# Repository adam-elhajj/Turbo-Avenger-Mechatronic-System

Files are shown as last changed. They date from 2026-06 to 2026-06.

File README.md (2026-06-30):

# Turbo Avenger: Autonomous Mechatronic Payload Delivery System

A high-precision, multi-actuator mechatronic system engineered for autonomous, search-and-rescue inspired payload delivery. Developed as a milestone cornerstone engineering project at the **University of Windsor**, this system automates the storage, sequencing, and deployment of three separate payloads to a static target under real-world constraints.

---

### 📺 System Verification & Demo
Click the player below to watch the **Turbo Avenger** execute its fully autonomous 3-stage delivery sequence:

Turbo Avenger Verification Demo (https://www.youtube.com/watch?v=t6WQirkNGkE)

---

## 🎯 Engineering & Performance Benchmarks
* **Targeting Precision:** Achieved an empirical accuracy of **±5 cm at a 3-meter range** (1.6% variance).
* **Autonomous Sequence:** 100% deterministic, human-out-of-the-loop sorting and deployment sequence.
* **Component Reliability:** Eliminated jamming bottlenecks using a custom dual-servo escapement architecture.
* **Fiscal Optimization:** Fully prototyped, value-engineered, and deployed within a strict **\$328 budget limit**.

---

## 🛠️ System Architecture & Visual Design

### ⚙️ Mechanical & Actuation Architecture
* **Energy Storage & Release:** Features a synchronized servo-driven energy storage system paired with a rotating latch mechanism for instantaneous power release.
* **Automated Autoloading:** Designed a dual-servo mechanical escapement subsystem to prevent multi-payload feeding failures and isolate system jams.
* **Design Validation:** Validated kinematic constraints and assembly interfaces via iterative **3D CAD modeling** and stress verification.

<table>
  <tr>
    <td><b>3D System Modeling</b></td>
    <td><b>Orthographic & Isometric Schematics</b></td>
  </tr>
  <tr>
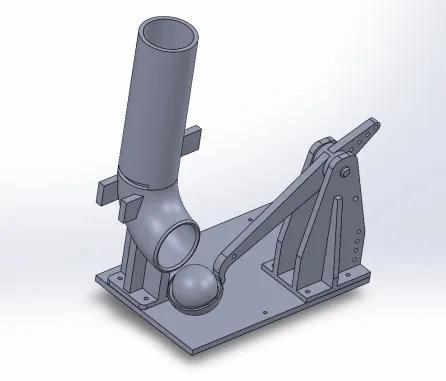
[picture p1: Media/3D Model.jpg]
3D Model
    <td></td>
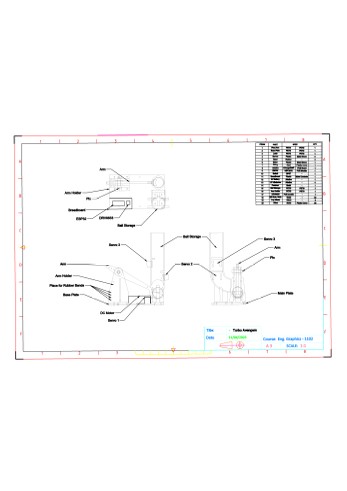
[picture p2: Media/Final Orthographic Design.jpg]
Orthographic Design
    <td></td>
  </tr>
</table>

### 🔌 Embedded Control Systems & Hardware Interface
* **Dual-MCU Architecture:** Implemented an **Arduino Uno R3** alongside an **ESP32** to handle strict real-time control, parallel processing constraints, and high-frequency state machine management.
* **State Machine & Timing Logic:** Programmed asynchronous timing models for precise actuator triggering, transition validation, and deterministic safety overrides.

<p align="center">
  <b>System Wiring & Electrical Interface Diagram</b><br>
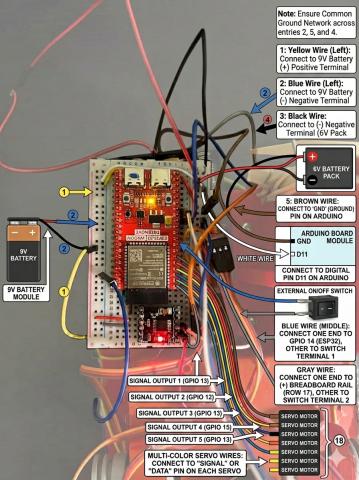
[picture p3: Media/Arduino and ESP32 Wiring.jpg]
Arduino and ESP32 Wiring Diagram
  
</p>

---

## 📂 Repository Tree Structure
```text
├── CAD-Models/                # Production Engineering Schematics
│   ├── Final Catapult assembly Team 221.dwg
│   ├── Top plate.dwg
│   └── Part_1_through_6.dwg   # Individual component layouts
├── Firmware/                  # Microcontroller Source Code
│   ├── Lunching_part_code/    # Actuator management & launch control scripts
│   └── Final-Line-Following.ino # Main path tracking algorithm script
├── Documentation/             # Engineering Specifications
│   ├── RobotCar_Part_List.pdf # Complete Bill of Materials (BOM)
│   ├── Final Proposal Report  # Technical design documentation
│   └── RFP_Amendments.pdf     # Engineering constraint compliances
└── Media/                     # Visual Assets & Portfolio Graphics
    ├── 3D Model.jpg
    ├── Arduino and ESP32 Wiring.jpg
    ├── Final Orthographic Design.jpg
    ├── Isometeric Drawing.jpg
    └── Turbo Avenger - Team#221 Poster.jpg
```

---

## 🛠️ Tools & Technologies Used
* **Languages:** C++, C (Embedded Arduino)
* **Hardware:** Arduino Uno R3, ESP32, High-Torque Servos, Electro-Mechanical Actuators
* **Software/CAD:** Autodesk AutoCAD, Git Version Control, Serial Data Analysis

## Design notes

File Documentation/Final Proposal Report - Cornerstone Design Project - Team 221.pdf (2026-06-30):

The Turbo Avenger: A Multi-Actuator Autonomous Payload Delivery System 2/52
#221

Turbo Avengers

Date: April 6, 2026
Submitted to: RHS Cornerstone Limited

Submitted by:
Adam El Hajj
Arian Navabpour
Lukas Waller
Drizzy Okunloa
Zion Odibeli

Executive Summary:

Turbo Avengers (Team 221) was commissioned by RHS Cornerstone Limited to develop an autonomous payload delivery system for hazardous search-and-rescue environments. The team engineered a servo-controlled elastic catapult featuring a synchronized three-actuator system for autonomous arming, loading, and firing. The prototype successfully met mission objectives by delivering exactly three payload units to a 30 × 40 cm target from a distance of 3 meters. With a total cost of $328.00, the system provides a robust, cost-effective, and repeatable solution. Testing confirmed that the dual-servo autoloader eliminates mechanical jams; however, precise timing control is required to maintain actuator synchronization. Overall, the Turbo Avenger demonstrates a reliable and scalable solution for autonomous payload delivery in hazardous environments.

TABLE OF CONTENTS

### 1.0 Introduction

### 1.1 Problem Statement

RHS Cornerstone Limited requires the development of an autonomous system capable of delivering emergency payloads into restricted search-and-rescue environments. The system must autonomously navigate a predefined course, stop precisely at a designated launch zone, and accurately deliver exactly three payload units into a 30 × 40 cm target area from a distance of 3 meters without human intervention. The solution must demonstrate high reliability, repeatability, and compliance with all physical and operational constraints.

### 1.2 Requirements

Functions:

The system must autonomously navigate a predefined course, stop precisely at the designated drop zone, sequentially reload payloads without failure, and execute three controlled and consistent launches to meet mission requirements.

Objectives:

The design aims to maximize launch accuracy within ±5 cm of the target, ensure highly repeatable and consistent performance across multiple trials, and minimize the likelihood of mechanical failure or jamming during operation.

Constraints:

The system is constrained to utilize elastic potential energy as the primary launch mechanism, fit entirely within the dimensional limits of the ELEGOO robotic chassis, and incorporate non-destructive mounting methods to preserve structural integrity and allow component reuse.

### 1.3 Background Research

The development of autonomous search-and-rescue systems requires the integration of reliable navigation with precise mechanical actuation. Murphy et al. (2011) emphasize that system reliability is the primary determinant of mission success, as failure in critical subsystems, specifically energy release mechanisms, which can result in total mission failure. Historically, projectile systems such as ballista-style catapults demonstrated effective methods of storing and releasing elastic potential energy. However, these systems relied heavily on human input, introducing variability in launch force, timing, and accuracy. Modern engineering solutions address these limitations through microcontroller-based automation and actuator synchronization. Smith and Jones (2022) found that replacing manual triggering mechanisms with digitally controlled systems significantly improves trajectory consistency by eliminating human-induced variability. Similarly, Lee and Patel (2019) highlight the importance of non-destructive system integration to maintain platform stability and ensure compatibility with onboard sensors and structural components. These findings had a direct impact on the design of the Turbo Avenger. The implementation of a synchronized three-actuator system, controlled by an Arduino UNO R3 and

ESP32, enables precise control of energy storage and release. The inclusion of a DRV8833 motor driver ensures accurate actuator coordination, resulting in consistent launch trajectories with an accuracy of approximately ±5 cm over a 3-meter range.

### 2.0 Proposed Design Details

### 2.1 Mechanical Architecture: Functional Description

The Turbo Avenger utilizes a pivoting launch arm powered by elastic potential energy to deliver payloads with consistent force and trajectory. The system operates using a synchronized three-actuator control system. The overall mechanical architecture of the Turbo Avenger is shown in Figure 1

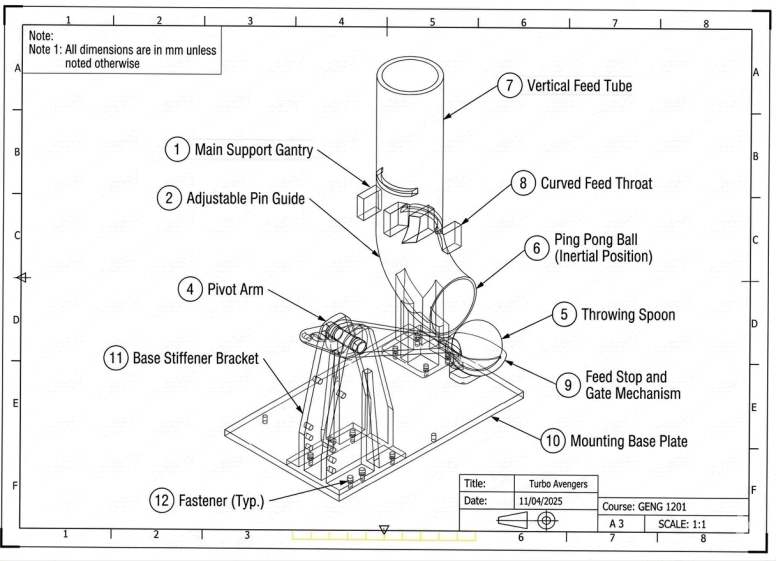
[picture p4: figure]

Figure 1: Mechanical architecture of the Turbo Avenger showing the pivoting launch arm, servo-driven pulley system, locking latch, and dual-servo autoloading mechanism.

The servo-driven pulley mechanism tensions the launch arm to a fixed and controlled position, directly supporting the objective of consistent trajectory output. This mechanism is powered through a DRV8833 motor driver, enabling reversible polarity for controlled autonomous arming and tension release. A locking servo latch secures the arm during loading and releases it on command, ensuring safe and controlled energy discharge. Additionally, a dual-servo autoloading mechanism delivers payloads sequentially, eliminating mechanical jamming and ensuring the system fulfills the requirement of reloading and launching exactly three payloads autonomously. This integrated design enables the system to perform all required functions, including autonomous navigation interfacing, precise stopping, sequential reloading, and controlled launching. The design meets all constraints by utilizing elastic potential energy, maintaining compatibility within the ELEGOO chassis dimensions, and employing non-destructive mounting techniques. Furthermore, this three-actuator architecture is inherently scalable and can be adapted for higher-load, full-scale applications such as industrial or emergency payload delivery systems while maintaining control precision and system reliability. Detailed engineering drawings are provided in Appendix B.

### 2.2 Full-Scale Concept

The full-scale system maintains the same three-actuator architecture validated by the prototype, with scaled structural components and actuation forces to support real-world deployment. The Turbo Avenger prototype represents a scaled version of an autonomous payload delivery system intended for search-and-rescue environments such as debris fields and restricted urban zones. The full-scale design extends the same three-actuator architecture to support real-world operation with increased payload capacity, durability, and range while maintaining fully autonomous functionality. In a full-scale implementation, payloads would include essential supplies such as medical kits, water, or survival materials. The autoloading mechanism can be scaled by enlarging the magazine to accommodate heavier payloads while preserving sequential, jam-free delivery. Structural components would be upgraded from PLA to high-strength materials such as carbon fibre or aerospace-grade aluminum to improve durability and reduce weight. The elastic launch system would be enhanced using higher-capacity torsion springs or reinforced tension elements to achieve greater launch distances while still satisfying the requirement to use stored elastic energy. Additionally, navigation and targeting would be improved through GPS and LiDAR integration to enable autonomous operation in complex, marker-less environments. Overall, the full-scale concept preserves the core three-actuator architecture validated by the prototype while scaling performance, materials, and control systems to meet real-world search-and-rescue requirements, all while remaining compliant with the original RFP constraints.

### 2.3 Prototype Performance

The performance of the Turbo Avenger prototype was validated through iterative trials on the simulated search-and-rescue course. The system was required to deliver three payloads into a 30 × 40 cm target area from a distance of 3 meters without human intervention. Testing demonstrated that the prototype met the required mission parameters under controlled conditions across multiple trials. The system achieved a trajectory accuracy of approximately ±5 cm, indicating consistent and repeatable launch behavior. The primary strength of the design is the high consistency of the synchronized three-actuator system. The servo-driven pulley maintains a fixed tensioning position, reducing variability between launches, while the dual-servo escapement operated reliably with no observed jams or loading failures during testing. A key limitation is the dependency on precise software timing for synchronization between the pulley release, latch mechanism, and autoloader cycle. Minor timing discrepancies in the control logic can affect launch consistency, requiring careful calibration and debugging to ensure reliable operation. Overall, the prototype met all functional requirements defined in the RFP during controlled testing.

### 2.4 Materials and Construction Methods

The mechanical components of the Turbo Avenger were modeled using SolidWorks and AutoCAD to ensure precise tolerances and proper integration of moving parts. Primary structural elements, including the pivoting arm and vertical magazine, were fabricated using Red Polylactic Acid (PLA) via 3D printing. This method was selected for its ability to produce complex geometries, support rapid prototyping, and maintain sufficient rigidity under elastic loading while minimizing weight. The system employs non-destructive mounting, using standardized stainless-steel fasteners to attach the 3D-printed base plate to the existing mounting points of the Arduino ELEGOO UNO R3 chassis. This approach preserves the integrity of the platform and allows for component reuse and modular assembly. Step-by-step assembly procedures are provided in Appendix A.

The selected materials and their functional roles are summarized in Table 2.

Table 2:

Primary Prototype Materials and Functional Applications

Material: | Application:
PLA | Pivot arm, base plate, magazine, latch
Rubber | Elastic bands and guides
Steel | Fasteners, axle, structural support
Nylon | Pulley tension string
Electronics | Arduino Uno, ESP32, motor driver, servos

### 3.0 Seventh Generation Principle Reflection

The Seventh Generation Principle originates from Haudenosaunee (Iroquois) philosophy and emphasizes that decisions made today should contribute to the well-being of future generations over a long-term horizon (EcoResolution, 2025). In engineering design, this principle is applied through considerations such as sustainability, safety, resource efficiency, modularity, and minimizing environmental impact across the system lifecycle (Murphy et al., 2011). The Turbo Avenger integrates these considerations by aligning its mechanical design, material selection, and system architecture with both present operational requirements and long-term sustainability objectives.

### 3.1 Historical Context (7 Generations Back)

Approximately 150 years ago, engineering practice during the industrial era prioritized mechanical functionality, productivity, and rapid technological advancement, often with limited attention to long-term environmental consequences or system safety. Mechanical systems from this period typically lacked modern control systems, standardized safety mechanisms, and fail-safe designs, which increased the likelihood of uncontrolled operation and resource inefficiency. This historical context highlights the evolution of engineering toward systems that emphasize reliability and safety. In response, the Turbo Avenger incorporates a locking servo latch mechanism to ensure controlled release of stored elastic energy. This design prevents unintended launches and reflects modern engineering standards for fail-safe operation. The inclusion of controlled actuation mechanisms reduces risks associated with mechanical energy storage systems and improves overall system reliability, aligning with lessons learned from earlier generations of mechanical design (Smith & Jones, 2022).

### 3.2 Present Reflection

The current design of the Turbo Avenger reflects contemporary engineering priorities, including efficiency, modularity, reliability, and responsible material usage. A key feature supporting these priorities is the use of a non-destructive mounting approach, allowing the system to be integrated with the ELEGOO chassis without permanent modification. This preserves the base platform for reuse and reduces material waste, supporting sustainable prototyping practices. In addition, the use of additive manufacturing (3D printing with PLA) enables rapid prototyping while minimizing fabrication waste compared to subtractive manufacturing methods. Although PLA is used in this prototype phase due to accessibility and ease of fabrication, its selection is consistent with iterative engineering practices that prioritize development efficiency and controlled material usage. The modular nature of the system also allows individual components to be replaced or upgraded without redesigning the entire assembly, further extending system usability and reducing long-term resource consumption (Lee & Patel, 2019).

### 3.3 Future Impact (7 Generations Forward)

Looking forward, the Turbo Avenger design is structured to support long-term adaptability, sustainability, and responsible technological development. Future iterations may incorporate biodegradable or recycled composite materials to reduce persistent environmental waste after the system’s lifecycle. Transitioning to more sustainable materials would mitigate the accumulation of non-degradable plastics and align the design with environmentally responsible engineering practices. Additionally, integrating renewable energy systems, such as solar-assisted charging, could reduce reliance on non-renewable energy sources and improve operational sustainability in remote or disaster-response environments. From a control systems perspective, upgrading the platform with sensor-based feedback mechanisms, such as ultrasonic or LiDAR sensing, would enhance adaptability in dynamic environments and reduce the need for physical redesigns. The system’s scalable architecture ensures that improvements can be implemented incrementally without replacing the entire design. This adaptability supports long-term usability and reduces lifecycle waste. Overall, the Turbo Avenger aligns with the Seventh Generation Principle by emphasizing safety, modularity, material responsibility, and forward-looking adaptability, ensuring that the design remains beneficial not only for current applications but also for future generations (Murphy et al., 2011).

### 4.0 Product Cost

The total financial investment required for the fabrication of the Turbo Avenger autonomous delivery prototype is $328.00 CAD. This cost includes the mobile navigation platform, the mechatronic actuation system, control electronics, and all structural components required for operation. A detailed breakdown of expenses, including component descriptions and procurement sources, is provided in Table 1.

Table 1:

Detailed Prototype Fabrication Cost Breakdown

Component | Description | Cost (CAD)
ELEGOO Smart Robot Kit | Mobile base with Arduino UNO R3 (ELEGOO, 2026) | $100.00
Custom 3D Printing | Red PLA material and fabrication | $141.00
Actuation System | 3× micro servo motors (Amazon, 2026) | $13.00
Control Electronics | ESP32, DRV8833 motor driver, breadboard | $36.00
Assembly Hardware | Stainless steel fasteners kit | $38.00
Total Prototype Cost | | $328.00

Note: Costs are based on current Canadian retail estimates and prototyping expenditures.

### 4.1 Cost Discussion

The total prototype cost of $328.00 CAD is considered reasonable for a functional autonomous system with integrated actuation, control, and mobility. The design leverages commercially available off-the-shelf components, which reduces development time and eliminates the need for expensive custom electronics or machined parts. The ELEGOO Smart Robot Kit provides a reliable and standardized mobile platform, allowing the team to focus resources on developing the payload delivery and actuation subsystems. Similarly, the use of 3D printing enables rapid iteration and customization of mechanical components while maintaining acceptable strength and precision for prototype validation. Although additive manufacturing represents a significant portion of the total cost, it is justified by the need for design flexibility and geometric complexity in the synchronized three-actuator mechanism. Overall, the cost reflects a balance between affordability, functionality, and scalability. The prototype demonstrates a cost-efficient engineering solution that can be further optimized for mass production through material substitution, component integration, and manufacturing process refinement.

### 5.0 Conclusions and Recommendations

### 5.1 Synthesis of Findings and Final Performance

The Turbo Avenger successfully demonstrates that a synchronized three-actuator system can achieve reliable autonomous payload delivery for search-and-rescue applications. Testing confirmed that the prototype met all primary requirements, consistently achieving a launch range of approximately 3 meters with a trajectory accuracy of ±5 cm while delivering three payloads within the designated 30 × 40 cm target area. The dual-servo electronic escapement significantly improved reliability by preventing double-feeds and eliminating jamming, enabling precise and repeatable payload release. The system also operated fully autonomously while remaining below the 1.5-meter height constraint, confirming that controlled elastic energy combined with coordinated actuation can meet both performance and safety requirements.

### 5.2 Technical Limitations and Lessons Learned

Testing identified software timing and actuator synchronization as the primary limitation. The system depends on tightly coordinated signals between the ESP32 and Arduino Uno to control the arming pulley, locking latch, and autoloader. Minor delays in execution can disrupt actuator sequencing, leading to inconsistent loading or firing. This highlights that system performance is constrained not only by mechanical design but also by control logic precision. While the hardware is structurally sound, the absence of closed-loop feedback reduces adaptability to dynamic conditions. The key lesson is that reliable mechanical systems must be supported by equally robust, real-time control to ensure consistent operation.

### 5.3 Recommendations for Implementation

Future improvements should focus on integrating real-time sensor feedback, such as ultrasonic or infrared sensing, to enable adaptive control of firing distance and improve responsiveness in changing environments. Upgrading the navigation system to incorporate GPS and LiDAR would allow operation in unstructured, marker-less environments. From a materials perspective, replacing PLA with biodegradable or recycled composites would reduce environmental impact and align the design with sustainability goals. Additionally, consolidating control into a more integrated microcontroller architecture would reduce communication delays and improve actuator synchronization. These enhancements would improve reliability, scalability, and sustainability, supporting deployment of the Turbo Avenger as a practical autonomous search-and-rescue system.

11

References

- EcoResolution. (2025, October 13). Seven generation thinking. EcoResolution. https://www.ecoresolution.earth/resources/seven-generation-thinking
- ELEGOO. (2026). Smart robot car kit documentation. https://www.elegoo.com/
- Handley, R., & Greywolf, C. (2024). The IMAGINE 7th Generation initiative. https://imagine7thg.org/
- Indigenous Corporate Training Inc. (2020, May 30). What is the Seventh Generation Principle? Working Effectively with Indigenous Peoples Blog. https://www.ictinc.ca/blog/seventh-generation-principle
- Lee, J., & Patel, R. (2019). Modular design approaches in mechatronic systems for improved reliability and maintainability. Journal of Mechatronic Systems Engineering, 12(3), 45–58.
- Murphy, R. R., Tadokoro, S., & Kleiner, A. (2011). Search and rescue robotics. In B. Siciliano & O. Khatib (Eds.), Springer handbook of robotics (pp. 1151–1173). Springer. https://doi.org/10.1007/978-3-540-30301-5_51
- Salfi-Novena, L. (2026). Lecture 10: The Seventh Generation Principle [Lecture notes]. GENG-1201, University of Windsor. Brightspace.
- Smith, A., & Jones, B. (2022). Automation of mechanical launch systems using microcontroller-based control. International Journal of Robotics and Automation, 37(2), 101–112.

12

Appendix A - Prototype Fabrication Instructions

How to Assemble and Fabricate the Turbo Avenger Prototype

### 1. Introduction

This manual provides a clear, step-by-step procedure for the assembly of the Turbo Avenger autonomous delivery system.

Target Audience: Engineering technicians or students familiar with basic hand tools and the Arduino IDE

Estimated Completion Time: 45–60 minutes

Required Equipment: Hex key set (2 mm, 2.5 mm), small Phillips screwdriver, needle-nose pliers, and a computer with Arduino IDE installed

### 2. Materials and Components List

- (1) ELEGOO Smart Robot Car Kit base
- (1) Custom 3D-Printed Base Plate (PLA)
- (1) Pivoting Launch Arm with payload cup
- (1) Vertical Magazine Tube
- (3) Micro Servos (SG90 or equivalent)
- (1) DC Motor with pulley attachment
- (4) High-tension elastic bands
- (1) Stainless steel bolt and nut kit

### 3. Assembly Procedure

Phase 1: Structural Mounting

1. Clear the top acrylic plate of the ELEGOO robot car to prevent obstruction of sensors and wheels.
2. Align the custom 3D-printed base plate with the existing mounting holes on the chassis, as shown in Figure A1.

13

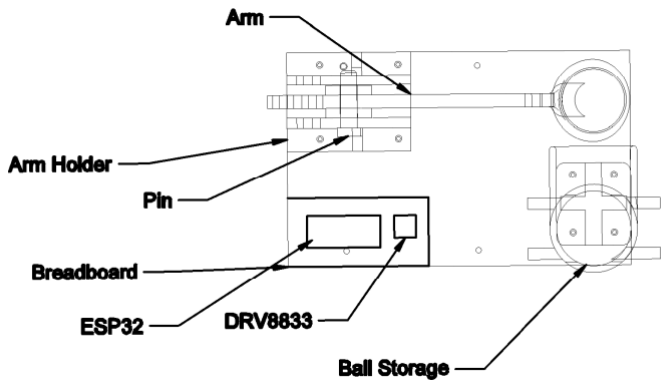
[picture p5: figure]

Figure A1: Orthographic view of the Turbo Avenger base plate alignment on the ELEGOO chassis.

3. Secure the base plate using four M3 bolts and nuts.

Note: Do not over-tighten fasteners, as PLA may crack under excessive stress.

Phase 2: Actuator Installation

4. Insert the locking servo into the designated rear slot on the base plate.
5. Attach the dual-servo autoloader to the vertical magazine tube using mounting brackets.
6. Mount the DC motor to the side frame to function as the arming pulley.

Phase 3: Launch Mechanism

7. Install the pivoting launch arm into the central axle support and secure it with the main pivot bolt.
8. Loop four high-tension elastic bands over the tensioning points on the arm and base.

Warning: Keep hands clear of the launch path during this step to prevent injury.

9. Thread the arming string from the motor pulley to the rear of the launch arm.

Phase 4: Electronics and Wiring

10. Connect the three servo signal wires to the ESP32 control interface.
11. Attach the DC motor leads to the DRV8833 motor driver.
12. Link the Arduino control pin to the ESP32 input pin to enable synchronized operation, as shown in Figure A2.

14

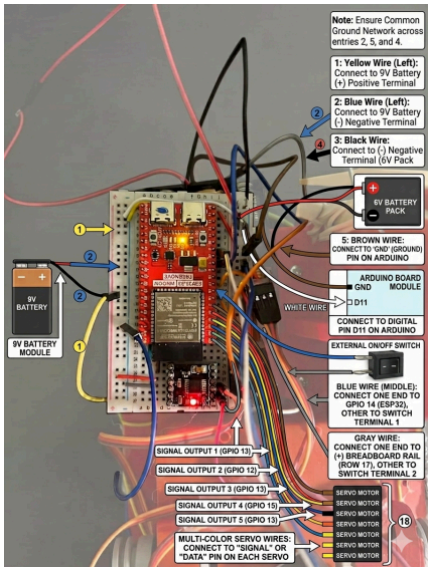
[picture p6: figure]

Figure A2: Actuator wiring configuration showing servo connections, ESP32 interface, and DRV8833 motor driver.

### 4. Final Check and Operation

13. Perform a manual dry run by rotating the pulley to confirm the arm engages the locking latch correctly.
14. Verify that all fasteners and connections are secure.
15. Upload the control program and initiate autonomous testing.

Conclusion

The assembly of the Turbo Avenger is now complete. Perform a manual “Dry Run” by rotating the pulley to ensure the arm catches the locking latch without obstruction before applying battery power. Once verified, upload the control code to initiate autonomous trials.

15

Appendix B - AutoCAD Drawing(s) of Design

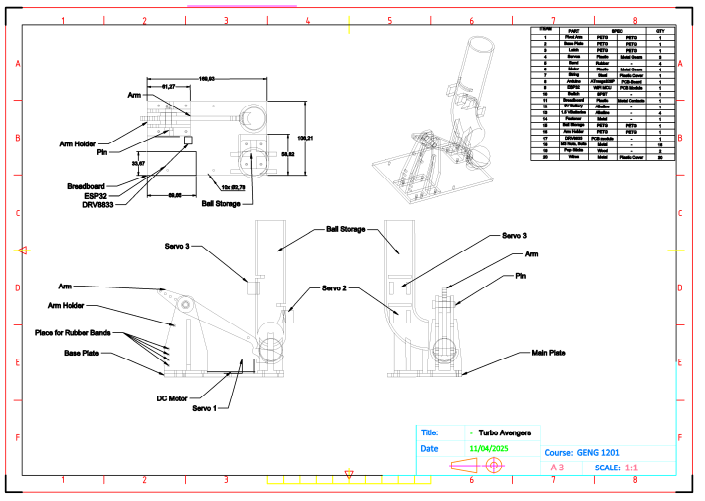
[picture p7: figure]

Figure B1: Fully dimensioned engineering drawing set of the Turbo Avenger prototype, including front, top, and right-side orthographic views and a 3D isometric model, illustrating component geometry, system integration, and compliance with chassis dimensional constraints.

16

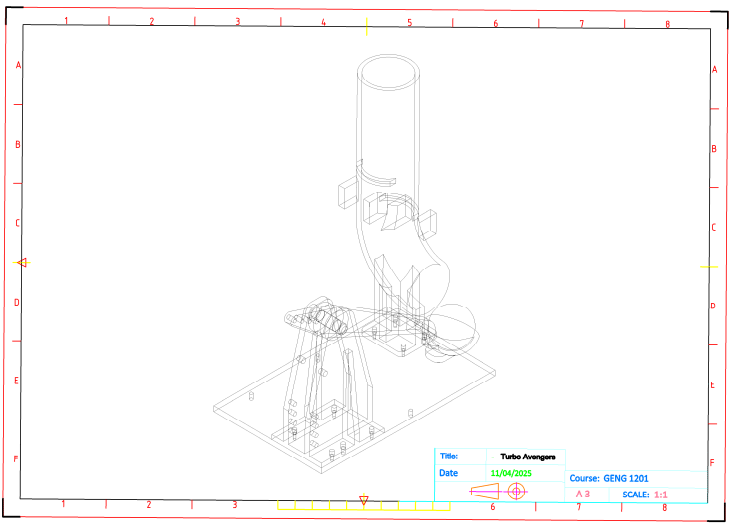
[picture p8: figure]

Figure B2: 3D isometric concept rendering of the Turbo Avenger system.

17

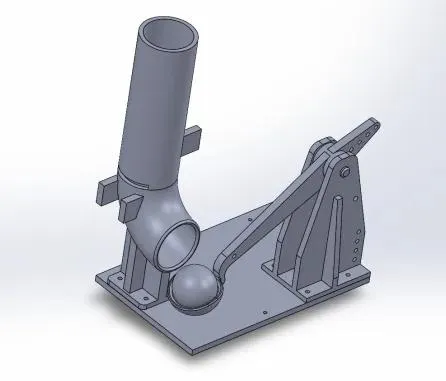
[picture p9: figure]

Figure B3: 3D AutoCad Model of the Turbo Avenger system.

18

Appendix C – Prototype Cost Breakdown Table

Table C1: Detailed Prototype Fabrication Cost Breakdown

The following table provides a comprehensive itemization of the materials and components utilized in the construction of the Turbo Avenger prototype. All costs are listed in Canadian Dollars (CAD) and reflect verified retail pricing and fabrication estimates.

Table C1:

Detailed Prototype Fabrication Cost Breakdown

Component | Technical Description & Source | Cost (CAD)
Mobile Base | ELEGOO Smart Robot Car Kit V4 (Arduino UNO R3 platform) (ELEGOO, 2026) | $100.00
Custom Structure | Red PLA 3D-printed components (pivot arm, base plate, magazine) (University of Windsor, 2026) | $141.00
Actuation System | 3× SG90 micro servo motors (Amazon, 2026) | $13.00
Control Mechatronics | ESP32 WROOM module, DRV8833 motor driver, breadboard (Electronic Supply, 2026) | $36.00
Mechanical Fasteners | Stainless steel M3/M4 bolt and nut kit (Home Hardware, 2026) | $38.00
Energy Storage | High-tension elastic bands (existing inventory) (Team Inventory, 2026) | $0.00*
TOTAL COST | | $328.00

Note. All pricing is based on Canadian retail estimates and university fabrication data. Items listed at $0.00 were sourced from existing inventory and are excluded from total procurement cost.

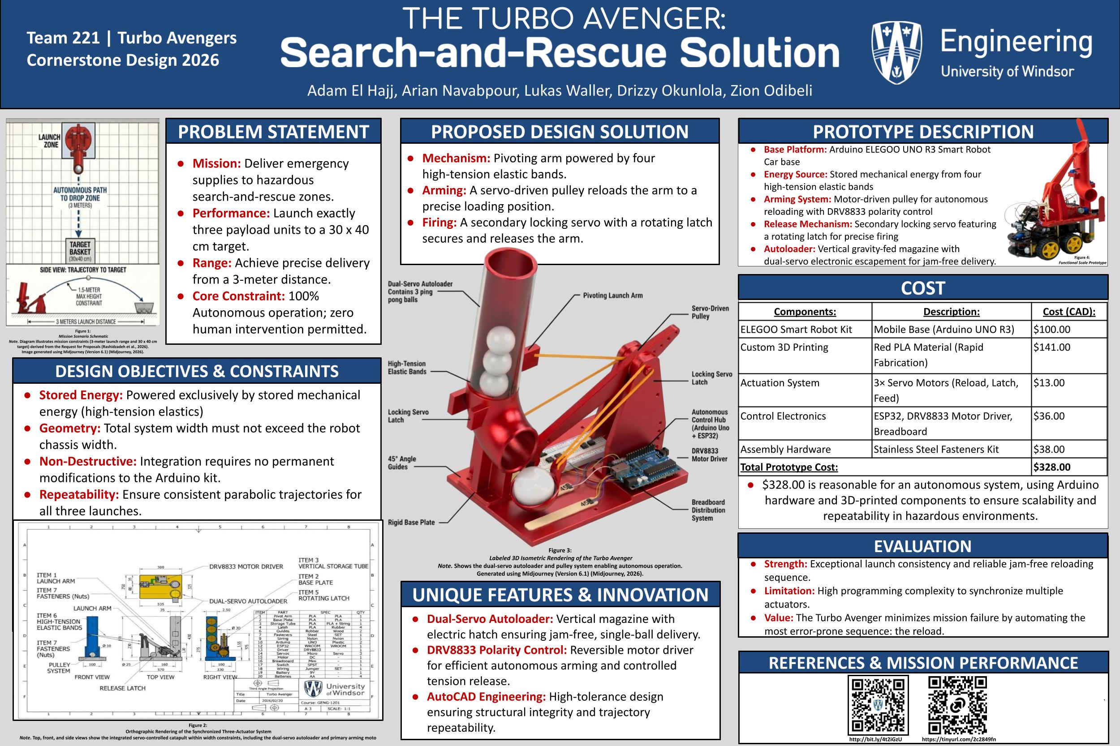
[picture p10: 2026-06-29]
Media/Turbo Avenger - Team#221 Poster.jpg

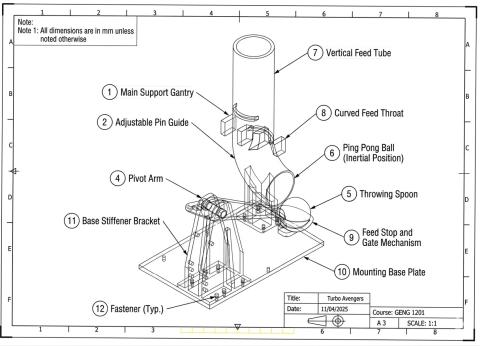
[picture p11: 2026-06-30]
Media/Isometeric Drawing.jpg

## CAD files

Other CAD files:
CAD-Models/Final Catapult assembly Team 221.dwg
CAD-Models/Part 2.dwg
CAD-Models/Part 6.dwg
CAD-Models/Part 1.dwg
CAD-Models/Part 3.dwg
CAD-Models/Top plate.dwg
CAD-Models/Final orthographic .dwg
CAD-Models/Part 4.dwg

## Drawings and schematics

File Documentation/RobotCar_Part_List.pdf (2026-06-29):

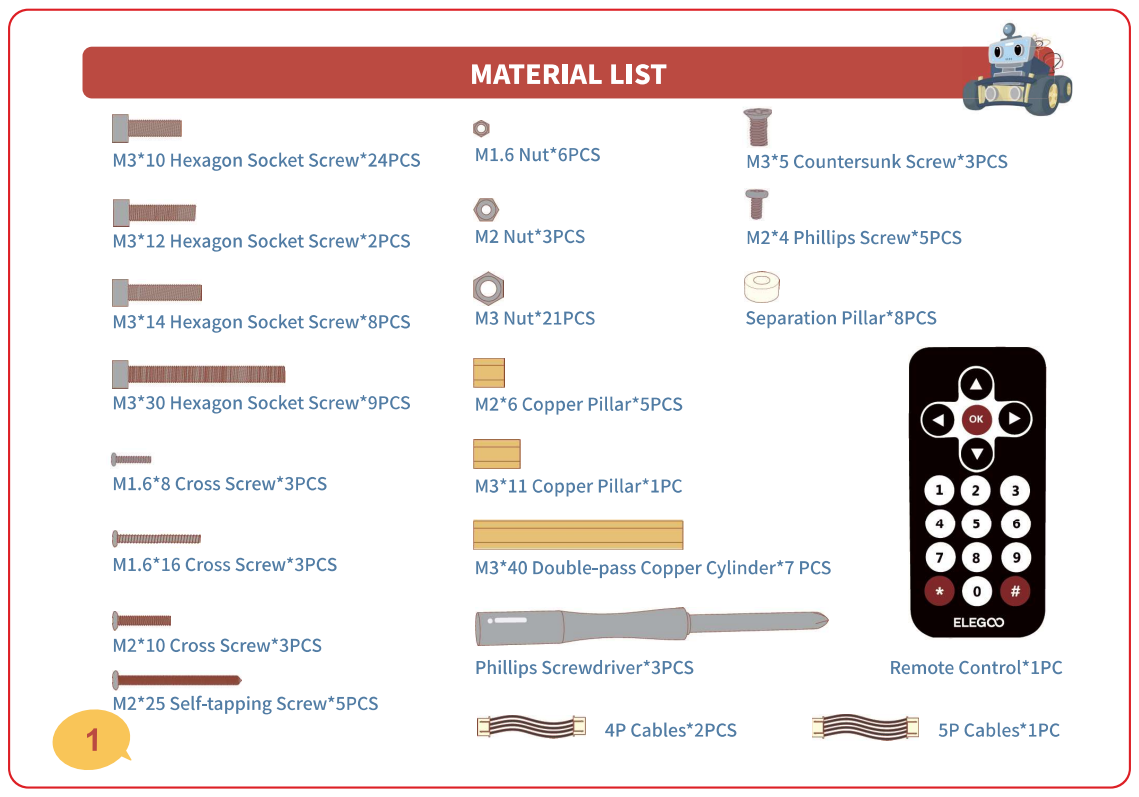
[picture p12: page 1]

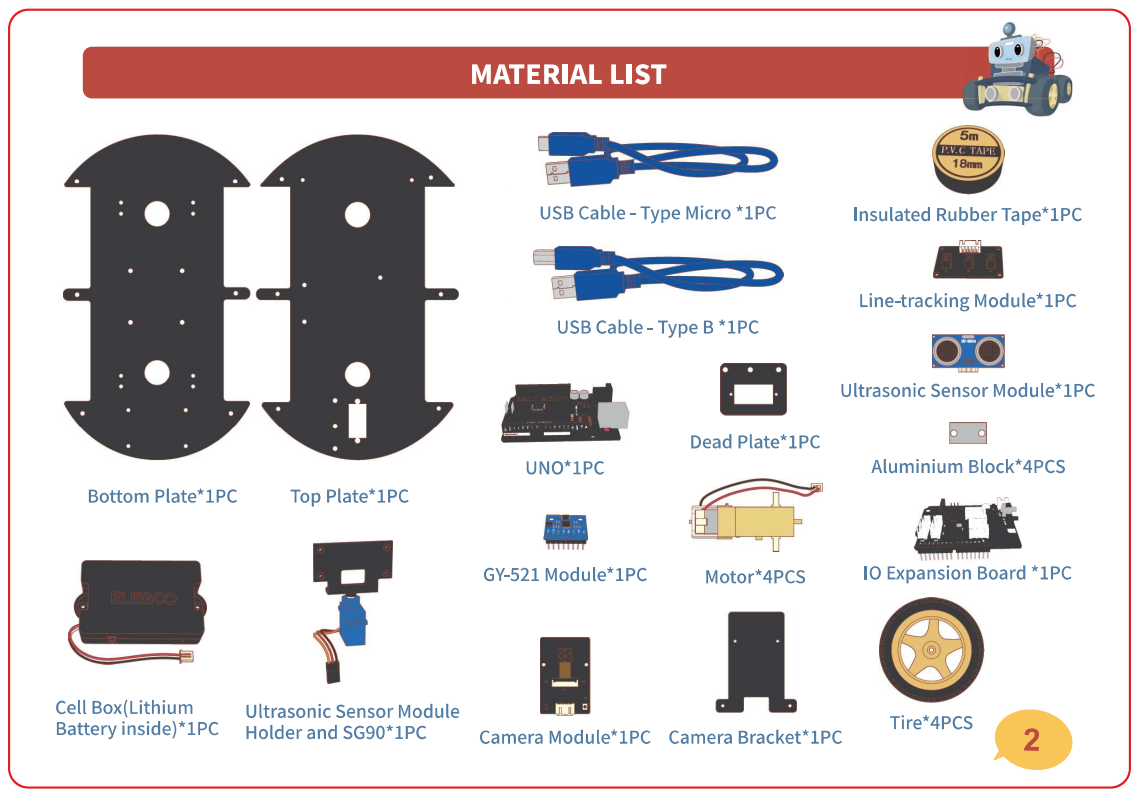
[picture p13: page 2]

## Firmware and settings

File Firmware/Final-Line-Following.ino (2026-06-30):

#include "GENG1201_Project.h"

// ------------------ LINE FOLLOW SETTINGS ------------------
unsigned long lostTime = 0;
bool searching = false;

// ------------------ HALLWAY SCAN SETTINGS ------------------
unsigned long lastScanTime = 0;

int SPEED_HALLWAY = 60;
int SPEED_LINE    = 90;
int SPEED_TURN    = 75;

int CENTER_TOL = 3;
int TURN_TIME  = 120;

// Ultrasonic servo 1 angles
int ANGLE_CENTER = 90;
int ANGLE_RIGHT  = 0;
int ANGLE_LEFT   = 180;

// White line thresholds (WHITE = LOWER)
int TH_M = 240;
int TH_L = 52;
int TH_R = 52;

// signal pin to other board
int SIGNAL_PIN = 11;

// Modes
enum Mode { HALLWAY, LINE_FOLLOW, STOP_DONE };
Mode mode = HALLWAY;

// Read ultrasonic distance
int readDistanceCM() {
  readUltrasonicSensor(get_Distance);
  return (int)get_Distance;
}

void setup() {
  Init();

  // ultrasonic servo center
  servoControl(ANGLE_CENTER);

  // keep signal pin inactive at startup
  pinMode(SIGNAL_PIN, INPUT);

  lastScanTime = millis();
  pinMode(SIGNAL_PIN, OUTPUT);
  digitalWrite(SIGNAL_PIN, LOW);


}

void loop() {
  int L = infraRed_L();
  int M = infraRed_M();
  int R = infraRed_R();

  bool Mw = (M <= TH_M);
  bool Lw = (L <= TH_L);
  bool Rw = (R <= TH_R);

  // ------------------ MODE 1: HALLWAY ------------------
  if (mode == HALLWAY) {

    // if line found, switch to line following
    if (Mw || Lw || Rw) {
      move(stop_it, 0);
      delay(120);
      searching = false;
      servoControl(ANGLE_CENTER);
      mode = LINE_FOLLOW;
      return;
    }

    // move forward while searching for line
    move(Forward, SPEED_HALLWAY);

    // every 2 seconds check walls and center robot
    if (millis() - lastScanTime >= 2000) {
      lastScanTime = millis();

      // look right
      servoControl(ANGLE_RIGHT);
      delay(250);
      int dR = readDistanceCM();

      // look left
      servoControl(ANGLE_LEFT);
      delay(250);
      int dL = readDistanceCM();

      // back to center
      servoControl(ANGLE_CENTER);
      delay(120);

      // correction
      if (dR - dL > CENTER_TOL) {
        move(Right, SPEED_TURN);
        delay(TURN_TIME);
        move(Forward, SPEED_HALLWAY);
      }
      else if (dL - dR > CENTER_TOL) {
        move(Left, SPEED_TURN);
        delay(TURN_TIME);
        move(Forward, SPEED_HALLWAY);
      }
    }

    delay(5);
    return;
  }

  // ------------------ MODE 2: LINE FOLLOW ------------------
  if (mode == LINE_FOLLOW) {

    L = infraRed_L();
    M = infraRed_M();
    R = infraRed_R();

    Mw = (M <= TH_M);
    Lw = (L <= TH_L);
    Rw = (R <= TH_R);

    // line found
    if (Mw || Lw || Rw) {
      searching = false;

      if (Mw) {
        move(Forward, SPEED_LINE);
      }
      else if (Rw) {
        move(Right, SPEED_LINE);
      }
      else if (Lw) {
        move(Left, SPEED_LINE);
      }
    }

    // line lost
    else {
      if (!searching) {
        searching = true;
        lostTime = millis();
      }

      // keep moving a little to confirm line really ended
      if (millis() - lostTime < 2000) {
        move(Forward, 70);
      }
      else {
        // final stop
        move(stop_it, 0);

        // NOW send signal to the other board
        mode = STOP_DONE;
      }
    }

    delay(5);
    return;
  }

  // ------------------ MODE 3: STOP ------------------
  
  if (mode == STOP_DONE) {
    move(stop_it, 0);
    // keep signal HIGH forever
    digitalWrite(SIGNAL_PIN, HIGH);
  }

}

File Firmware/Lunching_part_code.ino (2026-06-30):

#include <ESP32Servo.h>

const int IN1 = 42;
const int IN2 = 41;
const int buttonPin = 3;
const int enablePin = 9;
const int servoPin15 = 15;
const int servoPin16 = 16;
const int servoPin17 = 17;

Servo servo15;
Servo servo16;
Servo servo17;

// Waits until pin stays HIGH for holdMs consecutively
bool waitForStableHigh(int pin, unsigned long holdMs) {
  unsigned long highStart = 0;

  while (true) {
    if (digitalRead(pin) == HIGH) {
      if (highStart == 0) {
        highStart = millis();
      }

      if (millis() - highStart >= holdMs) {
        return true;
      }
    } else {
      highStart = 0;
    }

    delay(10);
  }
}

void setup() {
  pinMode(IN1, OUTPUT);
  pinMode(IN2, OUTPUT);
  pinMode(buttonPin, INPUT);
  pinMode(enablePin, INPUT);

  servo15.setPeriodHertz(50);
  servo16.setPeriodHertz(50);
  servo17.setPeriodHertz(50);

  servo15.attach(servoPin15, 500, 2400);
  servo16.attach(servoPin16, 500, 2400);
  servo17.attach(servoPin17, 500, 2400);

  digitalWrite(IN1, LOW);
  digitalWrite(IN2, LOW);

  servo15.write(90);
  servo16.write(90);
  servo17.write(180);

  delay(1000);

  // Wait for enable pin to stay HIGH for at least 1 second
  waitForStableHigh(enablePin, 1000);

  
  for (int i = 0; i < 3; i++) {
    bool servoMoved = false;

    // arm goes down
    digitalWrite(IN1, LOW);
    digitalWrite(IN2, HIGH);

    unsigned long startTime = millis();

    while (millis() - startTime < 3500) {
      // servo15 can move only after 1.9 sec from start of motor down movement
      if ((millis() - startTime >= 3330) && digitalRead(buttonPin) == HIGH && !servoMoved) {
        servo15.write(0);
        servoMoved = true;
      }
    }

    digitalWrite(IN1, LOW);
    digitalWrite(IN2, LOW);

    if (servoMoved) {
      delay(1000);

      // reverse motor for 2 sec
      digitalWrite(IN1, HIGH);
      digitalWrite(IN2, LOW);
      delay(1550);

      digitalWrite(IN1, LOW);
      digitalWrite(IN2, LOW);

      servo16.write(0);
      delay(2000);

      servo16.write(90);
      delay(2000);

      servo17.write(0);
      delay(1000);
      servo17.write(90);

      servo15.write(90);
    }

    delay(1000);
  }

  while (1) {
  }
}

void loop() {
}
